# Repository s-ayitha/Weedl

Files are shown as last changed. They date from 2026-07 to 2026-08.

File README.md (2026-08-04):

# Weedl
**An autonomous weed-pulling robot for residential backyards**

Weedl drives itself around a fenced yard, finds common backyard weeds (dandelions, first-year bull thistle, etc...), lines up with it, and mechanically uproots them.

>**Status:** In active development. The full system is designed and the compute/sensing stack is still being brought up. The robot is not yet fully assembled. See [Current Status](#current-status) for exactly what's going on.

## Why I built this
During the heat of the summer, uprooting weeds can become tedious, painful, and overall just a bad experience. 
Seeing how my dad went out and uprooted weeds nearly every day, I felt annoyed that something so easy and tedious had to be done by a person. I did some searching, just to see if our family could purchase a weed removal robot. Unfortunately, the only related robots that existed were industry/commercial grade.

Once I realized I could build my own robot that would uproot weeds for my dad, Weedl was born. I believe that autonomous robotics and AI shouldn't 
replace humans, but replace certain tasks that would other wise be a waste of time. Humans deserve to spend time doing more important things, like 
spending time with their family, and I hope Weedl can achieve this.

## What it is

Weedl is a small tracked robot that autonomously covers a backyard and removes weeds one at a time. It's built around two ideas:

1. **See and navigate like a real autonomous robot** Weedl builds a live map of the yard with a LiDAR, knows where it is within that map, plans a coverage path, and avoids obstacles, using software such as ROS2, SLAM, Nav2, and more!

2. **Uproot mechanically, not chemically** Instead of spraying chemicals into the same garden where fruits and vegetables are grown, Weedl uses a double pivot fork to dig into the roots of a weed and lever it out.

---
## How it works

### The Compute pair (Pi + Pico)

Weedl splits its computing across two processors on purpose:

**Raspberry Pi 5** runs the high-level autonomous under **ROS2 Jazzy**: SLAM, mapping, navigation, sensor fusion, weed detection, and the behavior logic. The pi acts as the brain.

**Raspberry Pi Pico** handles the realtime work: motor PID control, wheel encoder processing, servo timing, and an **independent safety watch dog**. Because it's separate from the Pi, it can cut the motors if the Pi ever fails.

The two talk over a **UART serial link**

### Sensing
**RPLiDAR C1** is connected to the Pi. It will be used to create a 2D 360 degree scan around the robot to detect obstacles and create a map.

**Arducam Camera Module 3 (IMX708)** is connected to the Pi. It's the most important sensor for weed detection. A lightweight model spots weeds and locates them on the ground.

**MPU-6050 IMU** used for orientation and motion sensing, fused with wheel odometry for a stable position estimate.

**HC-SR04 ultrasonic** used for low obstacle detection beneath the LiDAR's scan plane.

### Moving

A **tracked (tank style) chassis** with two encoder motors, is driven by a **Cytron MDD10A** dual-channel motor driver. Tracks let Weedl turn in place while maintaining grip on the ground.

### Uprooting

A **double-pivot fork** with chisel-ground tines, each pivot driven by a single **40 kg·cm DS3240MG servo**. A hood/fulcrum behind the tines acts as both a depth stop and a prying point. To insert, the fork drives into the soil beside the weed's root crown while the pivot servo adds a small, fast back-and-forth oscillation. This lets the tines work into firm soil using far less force than a straight push would need. Once inserted, the arm levers back against the hood, using it as a fulcrum to pop the root out rather than relying on the robot's own weight to hold it down.

### Power/Wiring
Weedl runs off a single 3S LiPo battery, split into three isolated voltage rails so a motor or servo current spike can't brown out the compute stack: **11.1V** straight to the drive motors, **7.4V** through a UBEC for the servos, and a regulated **5V** through a buck converter for the Pi and Pico. Everything shares a common ground, and the HC-SR04's ECHO line runs through a 1kΩ/2kΩ voltage divider to protect the Pico's 3.3V GPIO from the sensor's 5V signal.

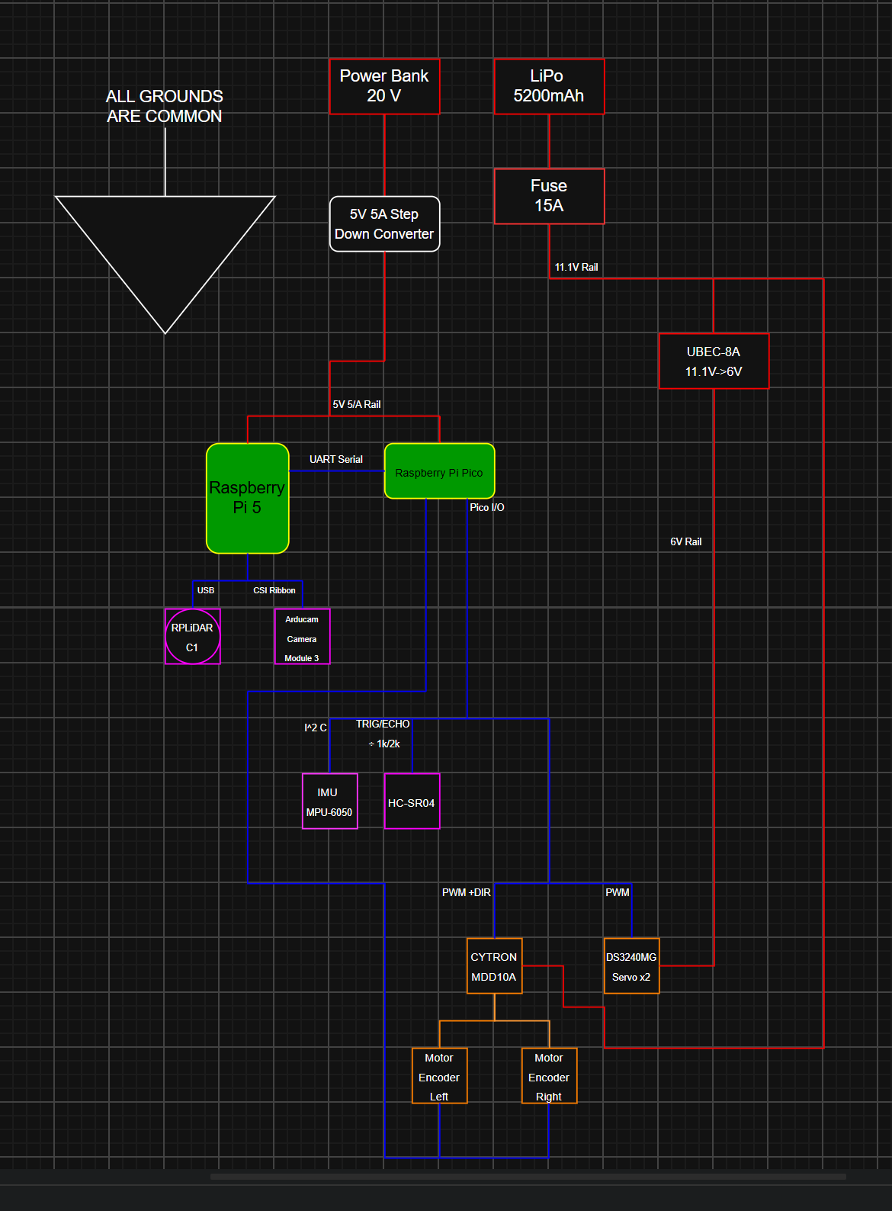
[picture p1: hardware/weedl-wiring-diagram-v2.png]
Weedl wiring diagram


## Software / autonomy stack







Running on the Pi under **ROS 2 Jazzy** (Ubuntu Server 24.04):

**slam_toolbox** - builds and maintains the map of the yard from LiDAR scans.

**Nav2** - pathplanning and obstacle avoidance

**robot_localization (EKF)** - fuses IMU and wheel odometry into a smooth position estimate.

**Weed detection** - a lightweight **TFLite** model runs directly on the Pi 5's CPU.

**Behavior state machine** — the core loop: `SEARCH → APPROACH → ALIGN → INSERT → PRY → RELEASE → RESUME`.

## Current Status

Weedl is currently being built

### Documentation
- [x] Bill of Materials
- [x] Wiring diagram
- [X] Schematic (KiCad) 
- [x] CAD for custom 3D-printed parts (arm, claw)

### Uprooting mechanism
- [x] Force analysis complete 
- [x] Arm and claw modeled and dimensioned
- [x] Steel tine layout finalized
- [ ] Pivot hole 
- [ ] Parts printed
- [ ] Tines cut, bent, and installed
- [ ] Mechanism assembled and bench-tested

### Compute & sensing
- [x] ROS2 Jazzy install process worked out and documented
- [x] RPLiDAR driver and odometry set up
- [ ] Pico firmware — motor control, encoder processing, servo timing, safety watchdog
- [ ] Nav2 / sensor fusion configuration
- [ ] Weed-detection model trained

### Chassis
- [x] Chassis selected and ordered
- [X] Physically assembled
- [ ] Mounting bracket for the arm — waiting on the chassis measurements above

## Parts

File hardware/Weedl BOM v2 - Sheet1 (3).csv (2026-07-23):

Category | Item | Exact Model | Qty | Link | Notes
Compute & Sensing | Raspberry Pi | Raspberry Pi 5 - 8 GB | 1 | https://vilros.com/products/raspberry-pi-5?variant=40065551302750
Compute & Sensing | 2D LiDAR | RPLiDAR C1 | 1 | https://www.amazon.com/gp/product/B0CMTXV5RC/ref=ewc_pr_img_4?smid=A3FZJTJP2FUJVA&psc=1
Compute & Sensing | Camera | Arducam Camera 3 Module 3 (IMX708) Autofocus | 1 | https://www.amazon.com/gp/product/B0BRY6MVXL/ref=ewc_pr_img_16?smid=A2FWW0KR82G0IH&th=1
Compute & Sensing | IMU | MPU-6050 | 1 | https://www.adafruit.com/product/3886
Compute & Sensing | SD Card | SANDISK Ultra 128GB microSD | 1 | https://www.amazon.com/gp/product/B0G8LLXFJH/ref=ewc_pr_img_1?smid=ATVPDKIKX0DER&th=1 | This just the one I had, may be overkill
Drive Base | Tracked Chassis | Shock Absorption Robot Tank Car Chassis for Raspberry Pi Encoder DC motors | 1 | https://www.amazon.com/Professional-Absorption-Raspberry-Suspension-Absorbing/dp/B0B6ZFQHF4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
Drive Base | Motor Driver | Cytron MDD10A dual-channel 10A (30A peak) 5-30V | 1 | https://www.robotshop.com/products/cytron-10a-5-30v-dual-channel-dc-motor-driver?gad_source=1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
Drive Base | Raspberry Pi Pico | Raspberry Pi Pico H - Pico with Headers Soldered | 1 | https://www.adafruit.com/product/5525
Manipulator | Arm+uproot servos | 40KG Digital Servo, DS3240MG 2 pack | 1 | https://www.amazon.com/HOOYIJ-DS3240MG-Waterproof-Steering-Airplane/dp/B0CNZRZY37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
Power | Main Batteries | 5200 mAh Lipo Battery 3S 80C | 1 | https://www.amazon.com/EMEPOVGY-Battery-5200mAh-Connector-Vehicles/dp/B0FSXSJK56 | Overkill, but actually cheaper + better reviews than weaker batteries
Power | Balance Charger | B3 LiPo 2S-3S Battery Balancer Charger 7.4V-11.1V | 1 | https://www.amazon.com/dp/B0D1MYBRNB?lv=shuf&redirect=true&channelId=500&plpRedirect=mhFallback
Power | Pichondria | USB-PD 2.0/3.0 to 5V 5A converter board for RPi5 | 1 | https://www.tindie.com/products/regaldreamtech/usb-pd-2030-to-5v-5a-converter-board-for-rpi5/
Power | Servo rail UBEC | UBEC-8A - 6-36V in - 7.4 - 8A cont / 16A burst | 1 | https://www.amazon.com/UBEC-8A-Servo-Independent-Supply-Airplane/dp/B0CN3429PF
Power | Low voltage alarm | Readytosky 1S-8S LiPo voltage checker / buzzer alarm | 1 | https://www.amazon.com/Readytosky-Battery-Monitor-Voltage-Indicator/dp/B01FHIMU0M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
Power | Main line fuse | 2 PCS 14 AWG Inline Fuse Holder | 1 | https://www.amazon.com/gp/product/B0DC3LZYT7/ref=ewc_pr_img_1?smid=A1030TMHUA1MYN&th=1
Power | Battery pig tails | OliYin XT60 male pigtail 14AWG pack | 1 | https://www.amazon.com/OliYin-3pairs-Connector-Silicone-Battery/dp/B074Y7CK6Z
Power | Power Bank | Anker Nano Power Bank A1259 | 1 | https://www.anker.com/products/a1259-built-in-cable-power-bank-10000mah?variant=42733233766550 | Any power bank 15V+ would work as long as its connected to the Pichondria
Obstacle & Misc | Ultrasonic sensors | HC-SR04 ultrasonic ranging module 2-pack | 1 | https://www.amazon.com/WWZMDiB-HC-SR04-Ultrasonic-Distance-Measuring/dp/B0B1MJJLJP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
Obstacle & Misc | Wiring & hardware | M3 hardware | 1 | https://www.amazon.com/gp/product/B0DRC9SQZ3/ref=ewc_pr_img_3?smid=A23XVIPJ96UME3&th=1
Obstacle & Misc | Wiring & hardware | resistor assortment for divider | 1 | https://www.amazon.com/gp/product/B0GJYWVLMV/ref=ox_sc_act_title_4?smid=A3JDHEAF9RIPJN&psc=1
Obstacle & Misc | Wiring & hardware | heat-shrink | 1 | https://www.amazon.com/650pcs-Shrink-Tubing-innhom-Approved/dp/B07WWWPR2X?sp_csd=d2lkZ2V0TmFtZT1zcF9hdGY
Obstacle & Misc | Arm/sensor brackets | 3D-printed (PETG recommended outdoors) | 1
Obstacle & Misc | Wiring & hardware | male to male jumper wires | 1 | https://www.adafruit.com/product/1957
Obstacle & Misc | Wiring & hardware | ELEGOO 3PCS 400 tie Points breadboard | 1 | https://www.amazon.com/gp/product/B01EV640I6/ref=ewc_pr_img_1?smid=A2WWHQ25ENKVJ1&psc=1
Obstacle & Misc | Wiring & hardware | STEMMA QT/Qwiic SH 4-pin to Male Headers Cable | 1 | https://www.adafruit.com/product/4209

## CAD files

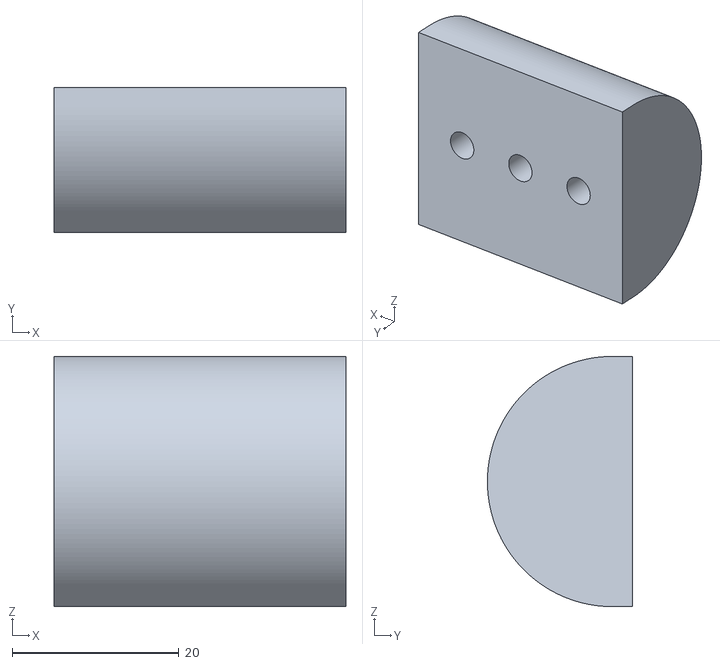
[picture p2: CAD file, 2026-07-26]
hardware/CAD/Weedl Claw v3.1.stl
35.0 x 17.4 x 30.0

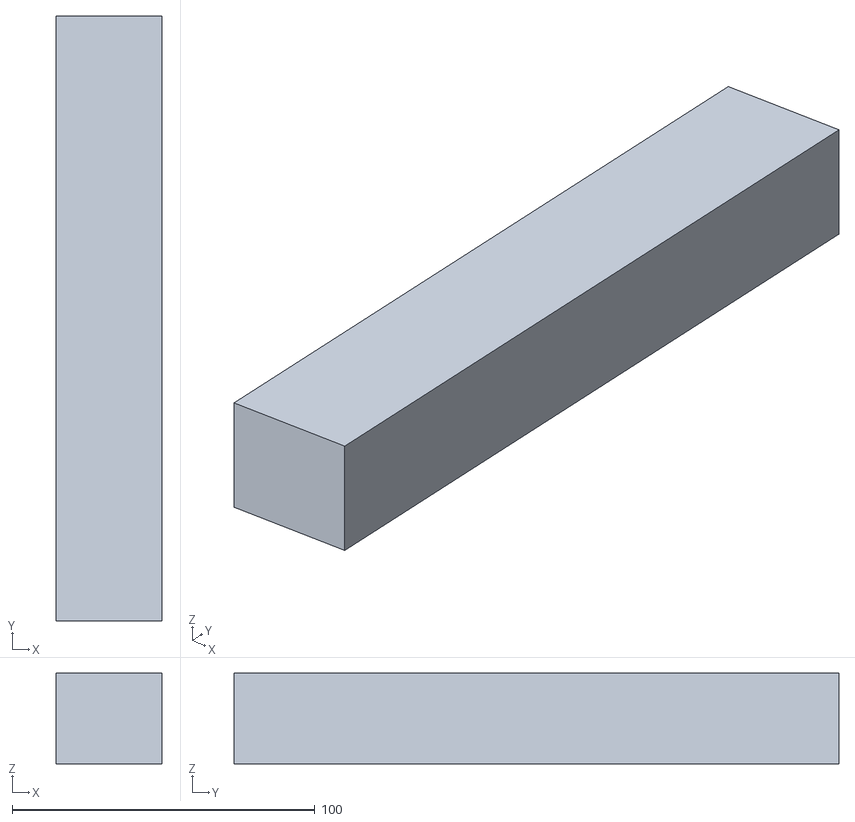
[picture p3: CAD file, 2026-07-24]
hardware/CAD/Part Studio 1 - Part 1 (1).stl
35.0 x 200.0 x 30.0

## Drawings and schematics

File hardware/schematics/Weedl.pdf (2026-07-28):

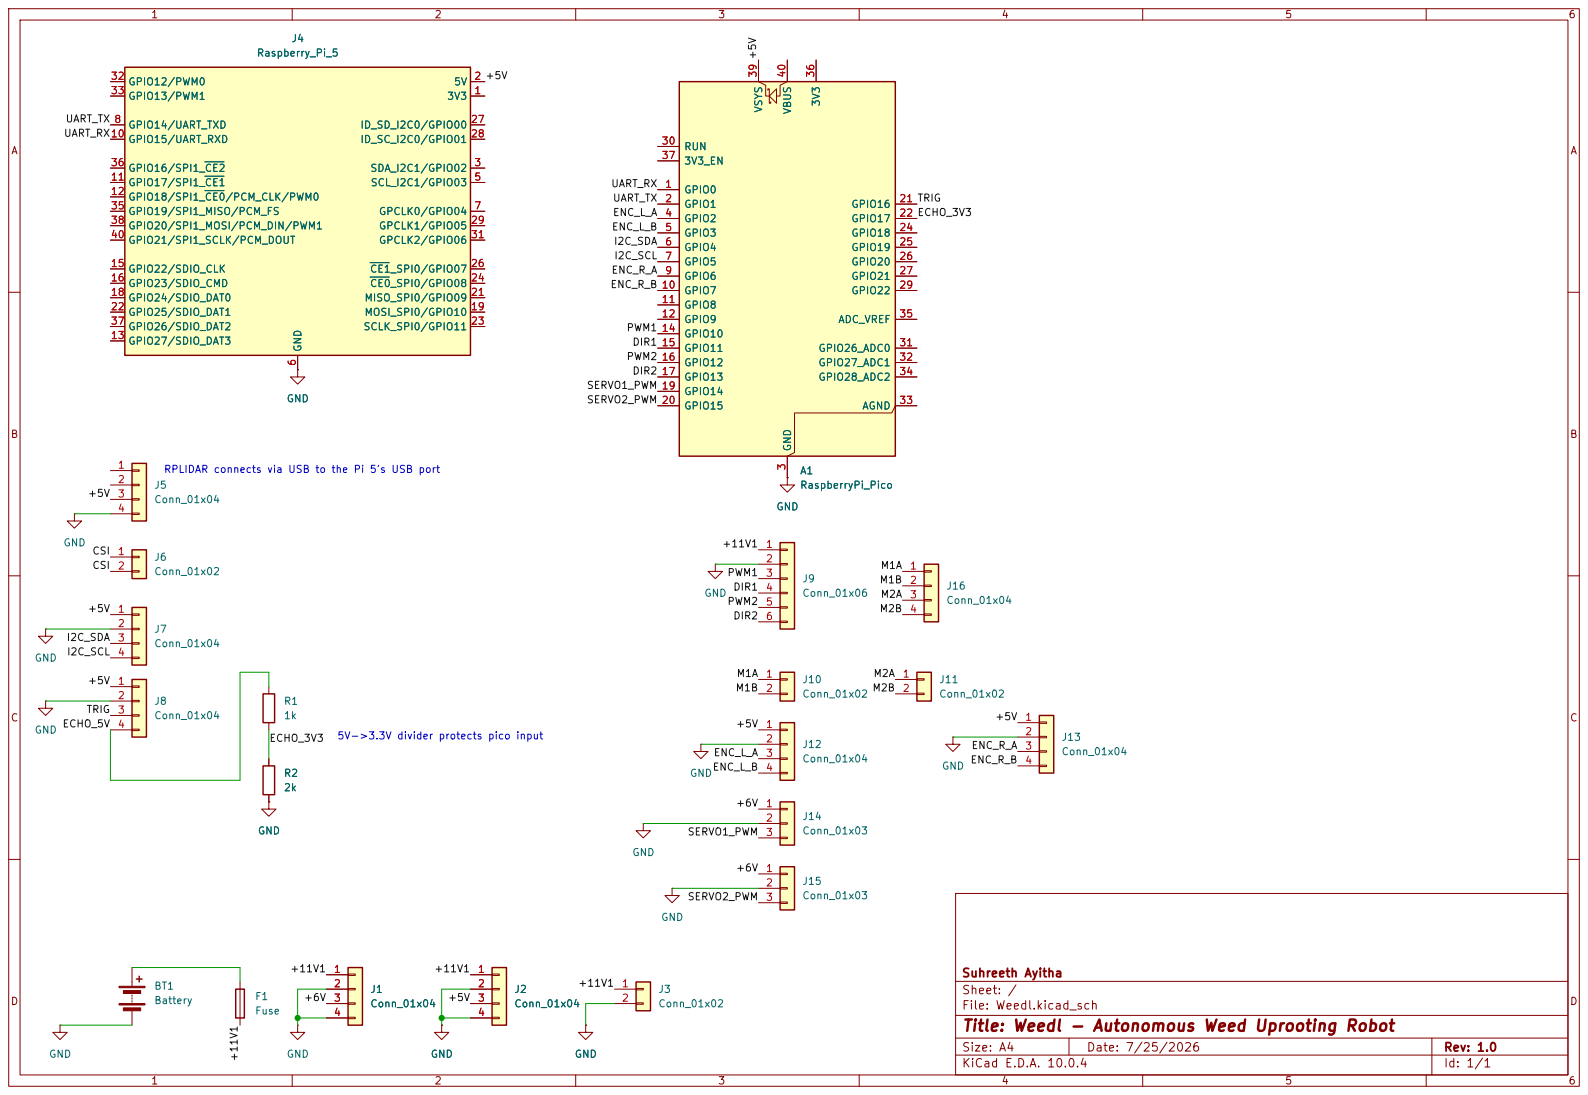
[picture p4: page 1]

Suhreeth Ayitha
Sheet: /
File: Weedl.kicad_sch
Title: Weedl - Autonomous Weed Uprooting Robot

Size: A4 | Rev: 1.0
KiCad E.D.A. 10.0.4 | Id: 1/1

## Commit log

2026-07-20 Added Wiring Diagram
2026-07-21 Bill Of Materials
    [Weedl BOM v2 - Sheet1 (2).csv]
2026-07-23 New BOM - chassis replacement
    Replaced the chassis with a better, more affordable one.
    [Weedl BOM v2 - Sheet1 (3).csv]
2026-07-23 Added Weedl Arm v3 CAD
    [Weedl Arm v3.stl]
2026-07-24 Weedl arm and claw v3.1
    [Part Studio 1 - Part 1 (1).stl, Part Studio 1 - Part 1 (2).stl]
2026-07-24 Rename CAD files
    [Weedl Arm v3.stl, Weedl Claw v3.stl]
2026-07-25 Wiring Diagram small update
2026-07-25 Wiring Diagram update
2026-07-25 Actual Update of Wiring Diagram
2026-07-26 New Claw
    [Weedl Claw v3.1.stl]
2026-07-29 New wiring diagram
    updated pichondria -> generic step down board
